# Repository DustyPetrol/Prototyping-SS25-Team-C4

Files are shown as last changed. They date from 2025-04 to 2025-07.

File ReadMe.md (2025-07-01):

# Prototyping SS25 Group C4

## [Final Report](Documentation/FinalReport/main.pdf)

## Distribution of tasks

| № | Task | Short summary | Responsible person | Deadline | Status |
|:---|:---|:---|:---|:---|:---|
| **1**  | 3D-modelling | Model and submit parts for 3D-printing: <br/> - motor holders<br/> - IR-sensor holders<br/> - battery/breadboard holder | [Oleg Kelner](https://github.com/eggcitedraccoon) | 24.04.25 | ✅ *Done* |
| **2**  | Requirements Diagram  | Create Requirements Diagram for the prototype | [Petr Lavrenov](https://github.com/DustyPetrol) | 27.04.25 | ✅ *Done* |
| **3**  | Use Case Diagram | Create Use Case Diagram for the prototype | [Petr Lavrenov](https://github.com/DustyPetrol) | 04.05.25 | ✅ *Done* |
| **4**  | Structure Diagram | Create Structure diagram for the prototype | [Petr Lavrenov](https://github.com/DustyPetrol) | 04.05.25 | ✅ *Done* |
| **5**  | State Machine Diagram | Create State Machine Diagram for the prototype | [Petr Lavrenov](https://github.com/DustyPetrol) | 04.05.25 | ✅ *Done* |
| **6**  | Tinkercad Simulation  | Create Tinkercad simulation of the prototype | [Oleg Kelner](https://github.com/eggcitedraccoon) | 04.05.25 | ✅ *Done* |
| **7**  | Assembling | Assemble the prototype: <br/> - fix 3D-printed parts on the chassis<br/> - solder power wires<br/> - connect everything | [Oleg Kelner](https://github.com/eggcitedraccoon) | 08.05.25 | ✅ *Done* |
| **8**  | 3D-modelling | Model and submit parts for 3D-printing: <br/> - ultrasonic holder<br/> - servo holder | [Oleg Kelner](https://github.com/eggcitedraccoon) | 05.05.25 | ✅ *Done* |
| **9**  | Programming | Make it follow the line | [Petr Lavrenov](https://github.com/DustyPetrol) | 15.05.25 | ✅ *Done* |
| **10** | Sequence Diagram | Create Sequence Diagram for the prototype | [Turja Barua](https://github.com/TurjabaruaGit) | 04.05.25 | ✅ *Done* |
| **11** | 3D-modelling | Model and submit parts for 3D-printing:<br/> - RGB-sensor holder | [Oleg Kelner](https://github.com/eggcitedraccoon) | 21.05.25 | ✅ *Done* |
| **12** | Programming | Unit tests | [Turja Barua](https://github.com/TurjabaruaGit) | 21.05.25 | ✅ *Done* |
| **13** | Programming | Implement `checkColor()` function | [Oleg Kelner](https://github.com/eggcitedraccoon) | 30.05.25 | ✅ *Done* |
| **14** | Programming | Implement *follow line* state machine | [Petr Lavrenov](https://github.com/DustyPetrol) | 30.05.25 | ✅ *Done* |
| **15** | Report | Prepare final project report | [Turja Barua](https://github.com/TurjabaruaGit) | 22.06.25 | ✅ *Done* |

## Project structure

### Documentation

```
Documentation/
|— Lectures/
|— Papyrus/
|— TinkerCad/
|— Assembly.png
```

`Lectures` contain lectures and other materials given by professors.

`Papyrus` contain **Papyrus** project with *SysML* diagrams.

`TinkerCad` contain **TinkerCad** simulation files (pic of the circuit and code).

`Assembly.png` - picture of the assembled prototype in 3D-modelling software.

### 3D models

```
3D models/
|— Basic components/
|— Details to print/
|— Assembly.iam 
```

`Basic components` contain 3D models of given components, such as Arduino Uno, battery, motors etc.

`Details to print` contain 3D-modeled parts for the printing (motor holder, IR-sensor holder etc.).

`Assembly.iam` - an assembly of the prototype made in **Autodesk Inventor**.

### Software

```
Software/
|— src/src.ino
```

`src/src.ino` - Arduino IDE main file.

## Additional materials

Useful **[Led Matrix Editor](https://ledmatrix-editor.arduino.cc/)**

**[Color sensor documentation](https://cdn-reichelt.de/documents/datenblatt/A300/SEN-COLOR_MANUAL_2021-08-18.pdf)**

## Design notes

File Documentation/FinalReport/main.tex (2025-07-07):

\documentclass[conference]{IEEEtran}
\IEEEoverridecommandlockouts

\usepackage{cite}
\usepackage{amsmath,amssymb,amsfonts}
\usepackage{algorithmic}
\usepackage{graphicx}
\usepackage{textcomp}
\usepackage{xcolor}
\usepackage{hyperref}
\usepackage{listings}
\usepackage{float}

\newcommand{\BibTeX}{\textrm{B \kern -.05em \textsc{i \kern -.025em b} \kern -.08em
T \kern -.1667em \lower .7ex \hbox{E} \kern -.125emX}}

\begin{document}

    \title{Design and Implementation of a Line Following and Obstacle Avoidance Robot}

    \author{
        \IEEEauthorblockN{Oleg Kelner\IEEEauthorrefmark{1}, Petr Lavrenov\IEEEauthorrefmark{1}, Turja Barua\IEEEauthorrefmark{1}}
        \IEEEauthorblockA{\IEEEauthorrefmark{1}Systems Engineering and Prototyping, BSc Electronic Engineering\\
        Hochschule Hamm-Lippstadt, Lippstadt, Germany\\
        \{oleg.kelner, petr.lavrenov, turja.barua\}@stud.hshl.de}
    }

    \maketitle

    \begin{abstract}
        This paper presents the design, development, and implementation of an autonomous mobile robot capable of both line following and obstacle avoidance. The project was conducted as part of a university prototyping course, focusing on integrating hardware components such as infrared sensors, ultrasonic modules, and servo motors with an Arduino-based control system. The robot's behavior is governed by a state machine model to ensure reliable navigation and quick response to environmental changes. Supporting tools like 3D modeling for hardware mounting, Tinkercad for simulation, and SysML for system-level design were used throughout the development process. The final prototype demonstrates effective performance in real-time scenarios, providing a practical understanding of embedded systems, control logic, and systems engineering principles.
    \end{abstract}

    \begin{IEEEkeywords}
        Autonomous robot, Line following, Obstacle avoidance, Arduino, Embedded systems, Infrared sensor, Ultrasonic sensor.
    \end{IEEEkeywords}

    \section{Introduction}\label{sec:introduction}

    This project focuses on building a simple autonomous robot that can follow a line and avoid obstacles using basic sensors. The robot is controlled by an Arduino Uno and uses infrared sensors to detect the line and an ultrasonic sensor to measure distance from obstacles. We used a step-by-step design process that included system modeling, 3D printing of parts, and simulation in Tinkercad. A state machine was used in the software to control how the robot switches between line-following and obstacle-avoidance modes. The goal was to learn how to combine hardware and software to create a working prototype.
    \section{System Design and Engineering}\label{sec:system-design-and-engineering}
    \begin{figure}[H]
        \centering
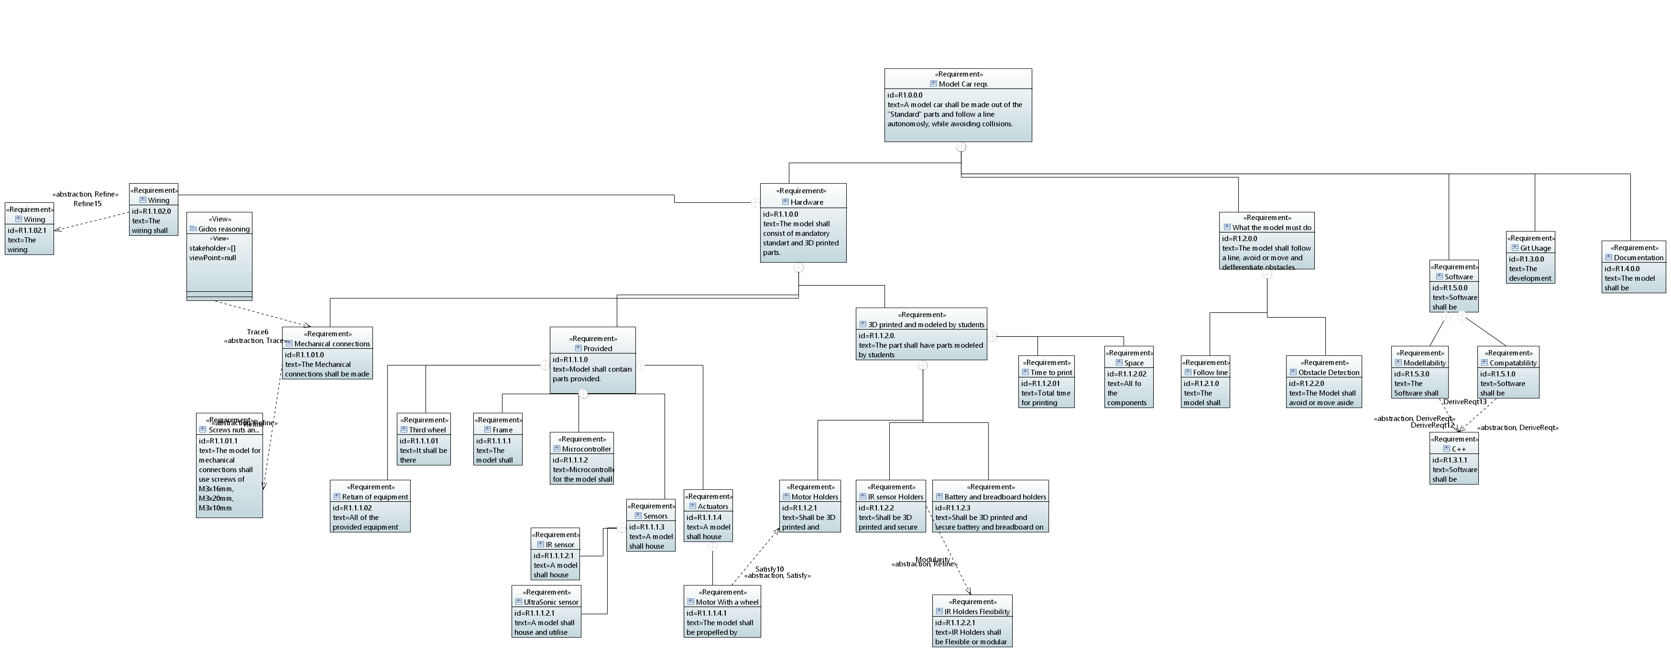
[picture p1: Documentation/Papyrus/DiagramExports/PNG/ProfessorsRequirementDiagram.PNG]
        
        \caption{ProfessorsRequirementDiagram (full page view in Appendix A)}
    \end{figure}
    \begin{figure}[H]
        \centering
        \begin{minipage}{0.48\linewidth}
            \centering
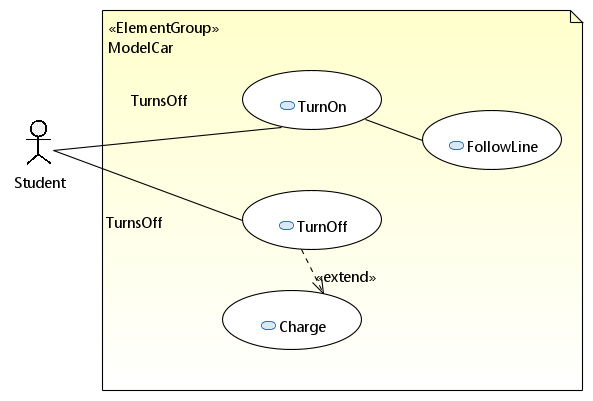
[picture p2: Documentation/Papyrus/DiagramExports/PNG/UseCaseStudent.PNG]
            
            \caption{Use Case Diagram(Student)}
            \label{fig:usecase_student}
        \end{minipage}
        \hfill
        \begin{minipage}{0.48\linewidth}
            \centering
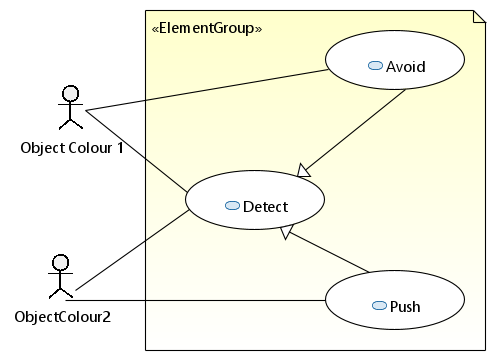
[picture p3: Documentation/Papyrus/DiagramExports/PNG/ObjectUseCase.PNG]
            
            \caption{Use Case Diagram(Object-Oriented)}
            \label{fig:object_usecase}
        \end{minipage}
    \end{figure}

    \begin{figure}[H]
        \centering
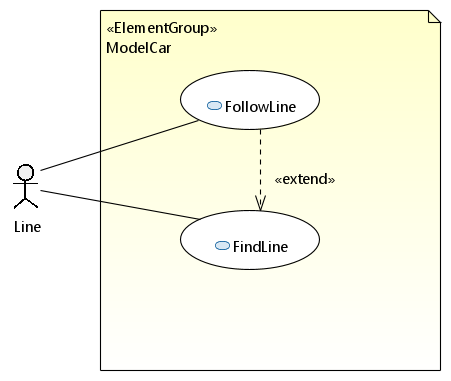
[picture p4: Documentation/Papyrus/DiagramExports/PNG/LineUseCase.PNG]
        
        \caption{LineUseCase}
        \label{fig:line_usecase}
    \end{figure}

    \begin{figure}[H]
        \centering
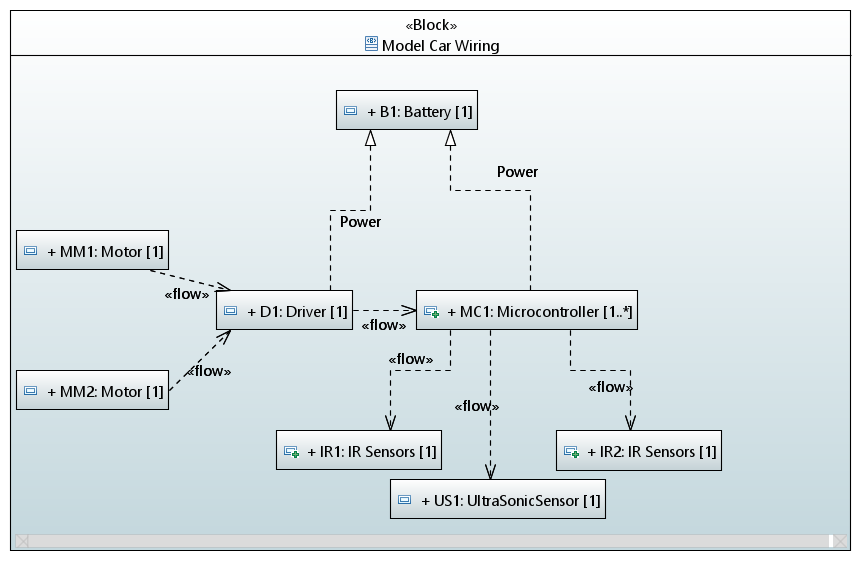
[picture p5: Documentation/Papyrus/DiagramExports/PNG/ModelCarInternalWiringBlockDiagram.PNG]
        
        \caption{ModelCarInternalWiringBlockDiagram}
        \label{fig:ModelCarInternalWiring_BlockDiagraml}
    \end{figure}
    \begin{figure}[H]
        \centering
        \begin{minipage}{0.48\linewidth}
            \centering
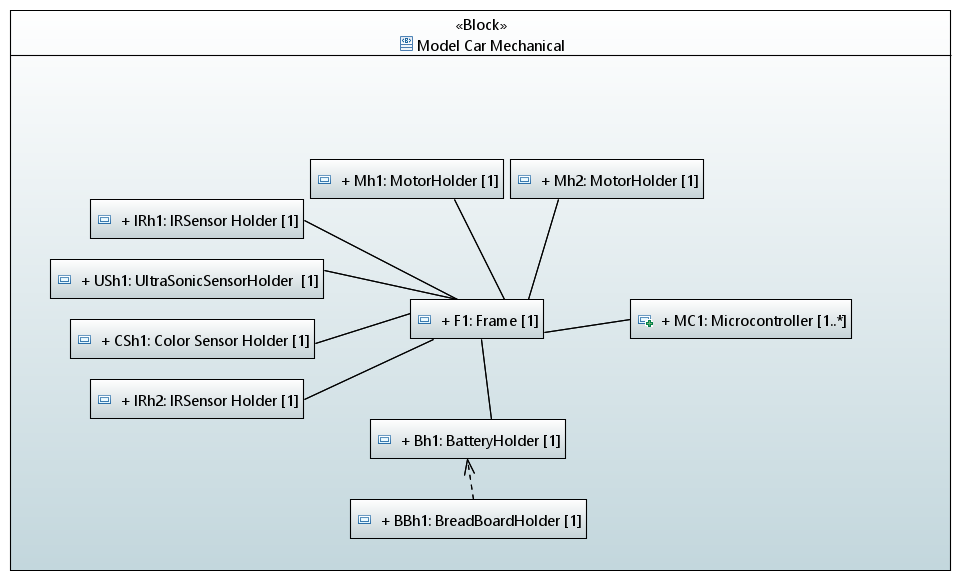
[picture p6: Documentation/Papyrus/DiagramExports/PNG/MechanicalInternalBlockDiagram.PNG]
            
            \caption{Mechanical Internal Block Diagram}
            \label{fig:MechanicalInternal_BlockDiagram}
        \end{minipage}
        \hfill
        \begin{minipage}{0.48\linewidth}
            \centering
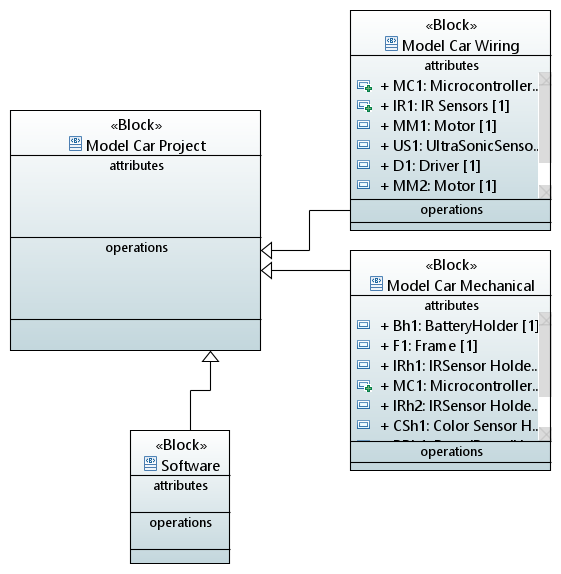
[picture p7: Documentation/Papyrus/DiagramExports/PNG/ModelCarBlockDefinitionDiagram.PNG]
            
            \caption{Model Car Block Definition Diagram}
            \label{fig:ModelCarDiagram_BlockDefinition}
        \end{minipage}
    \end{figure}

    \section{Prototyping and Design}\label{sec:prototyping-and-design}

    \subsection{Electronic Components}\label{subsec:electronic-components}
    The robot was built using a combination of basic electronic components. An Arduino Uno served as the central controller, processing sensor inputs and controlling the motors. Infrared (IR) sensors were used to detect the line path, while an ultrasonic sensor was employed for obstacle detection. A pair of DC motors provided movement, and the motor driver controlled their direction and speed. A breadboard and jumper wires were used to connect all components during testing and prototyping.

    \subsection{Virtual and Physical Prototypes}\label{subsec:virtual-and-physical-prototypes}
    All components were mounted onto a custom laser-cut wooden chassis. The Arduino board, breadboard, and motor driver were securely placed, and wiring was organized for stable operation. The ultrasonic sensor is mounted on a servo motor to allow directional scanning. The wheels are driven by DC motors placed at the rear, and all parts are powered via a shared voltage rail.
    \begin{figure}[H]
        \centering
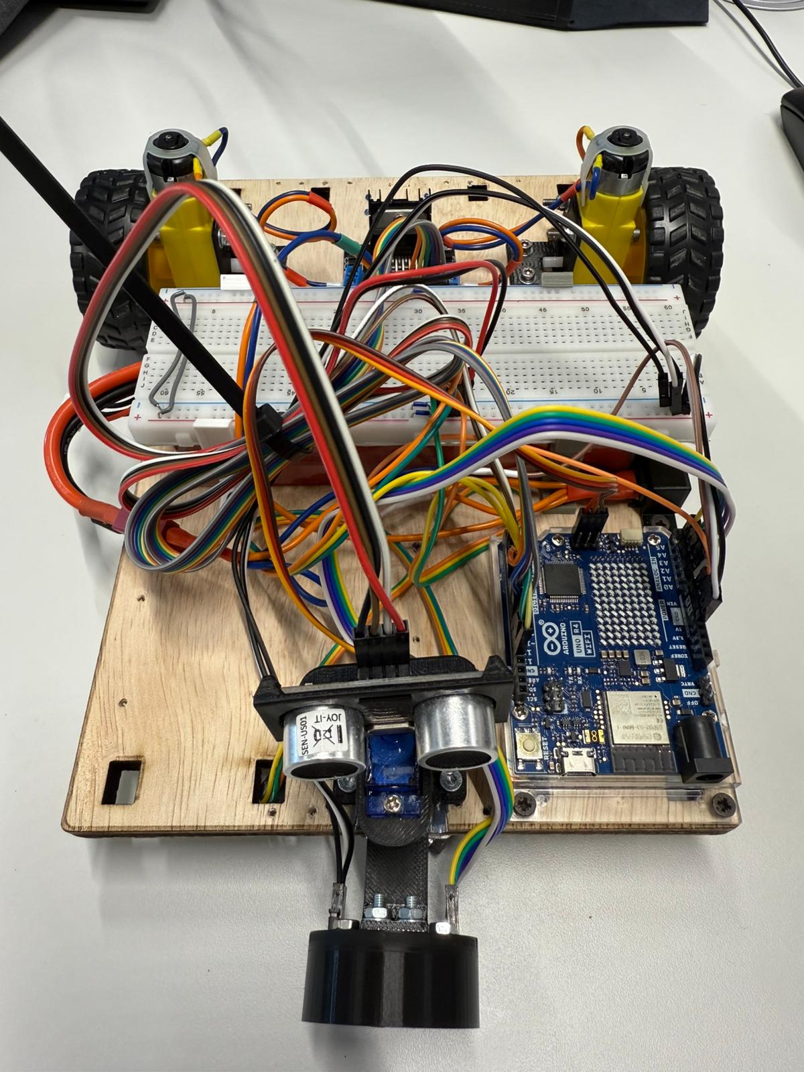
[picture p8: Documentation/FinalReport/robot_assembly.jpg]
        
        \caption{Robot Assembly}
    \end{figure}

    \subsection{Hardware Assembly}\label{subsec:hardware-assembly}
    All components were securely mounted on a custom-designed chassis and connected according to the system schematic. The IR sensors, ultrasonic sensor, motor driver, and Arduino Uno were all arranged for optimal functionality and accessibility.
    To better suit the physical layout and wiring constraints, the entire robot assembly was reversed, meaning the front-facing sensors and drive motors were reoriented to face the opposite direction. This design change ensured improved cable management, balanced weight distribution, and more efficient component interaction during operation.

    \begin{figure}[H]
        \centering
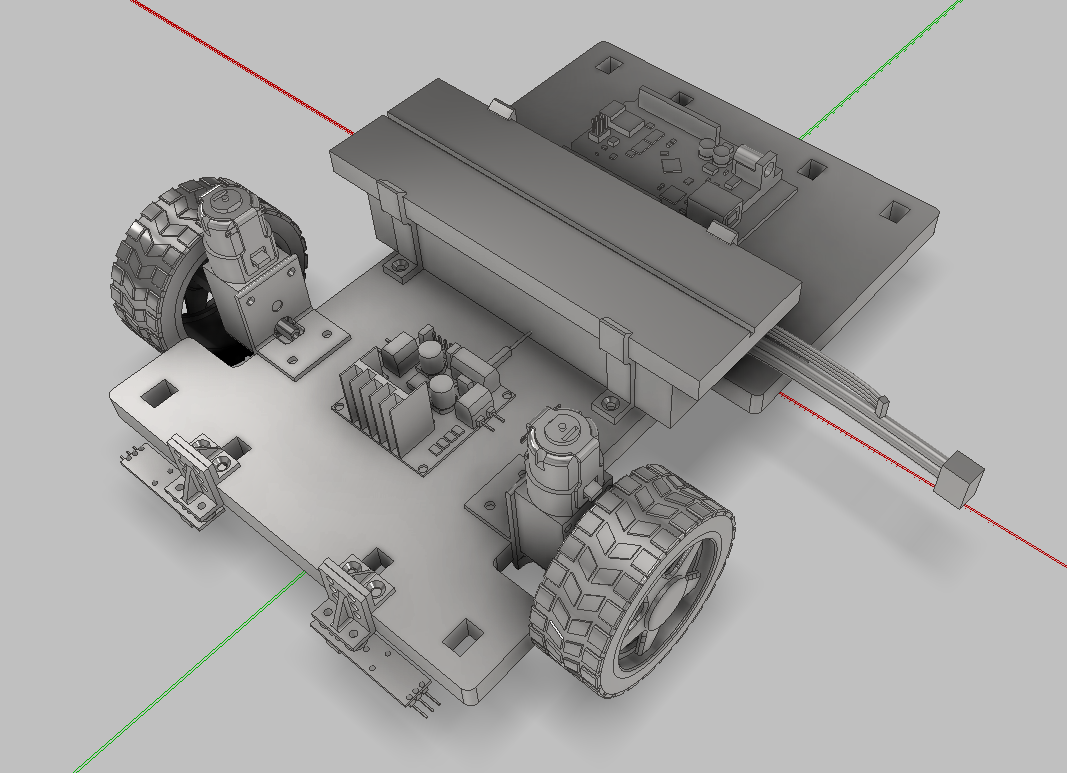
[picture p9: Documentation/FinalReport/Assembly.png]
        
        \caption{Assembly}
    \end{figure}
    \begin{figure}[H]
        \centering
        \begin{minipage}{0.48\linewidth}
            \centering
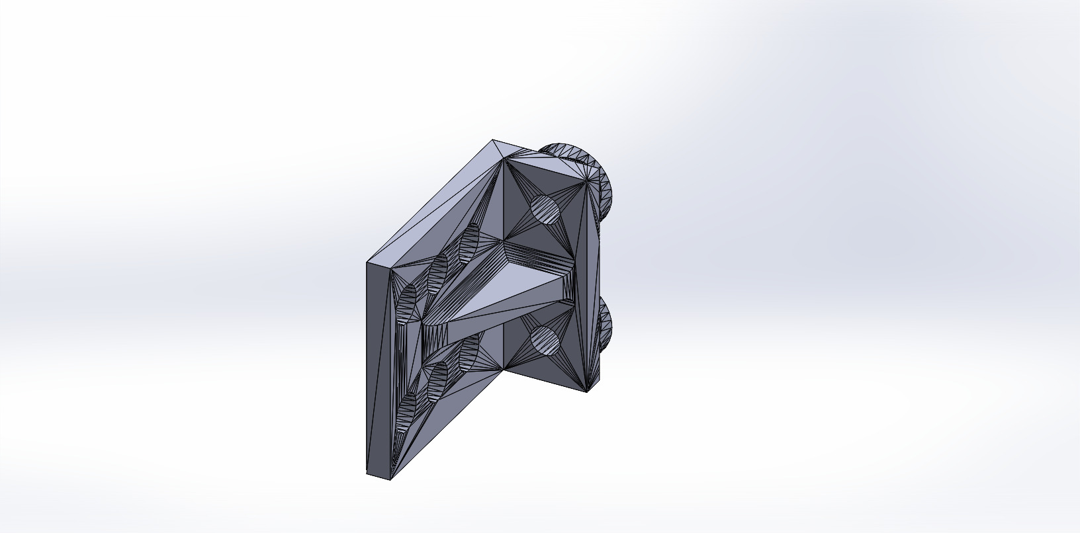
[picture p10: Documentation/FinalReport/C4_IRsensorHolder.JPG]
            
            \caption{IR Sensor Holder 1}
            \label{fig:IRsensorHolder1}
        \end{minipage}
        \hfill
        \begin{minipage}{0.48\linewidth}
            \centering
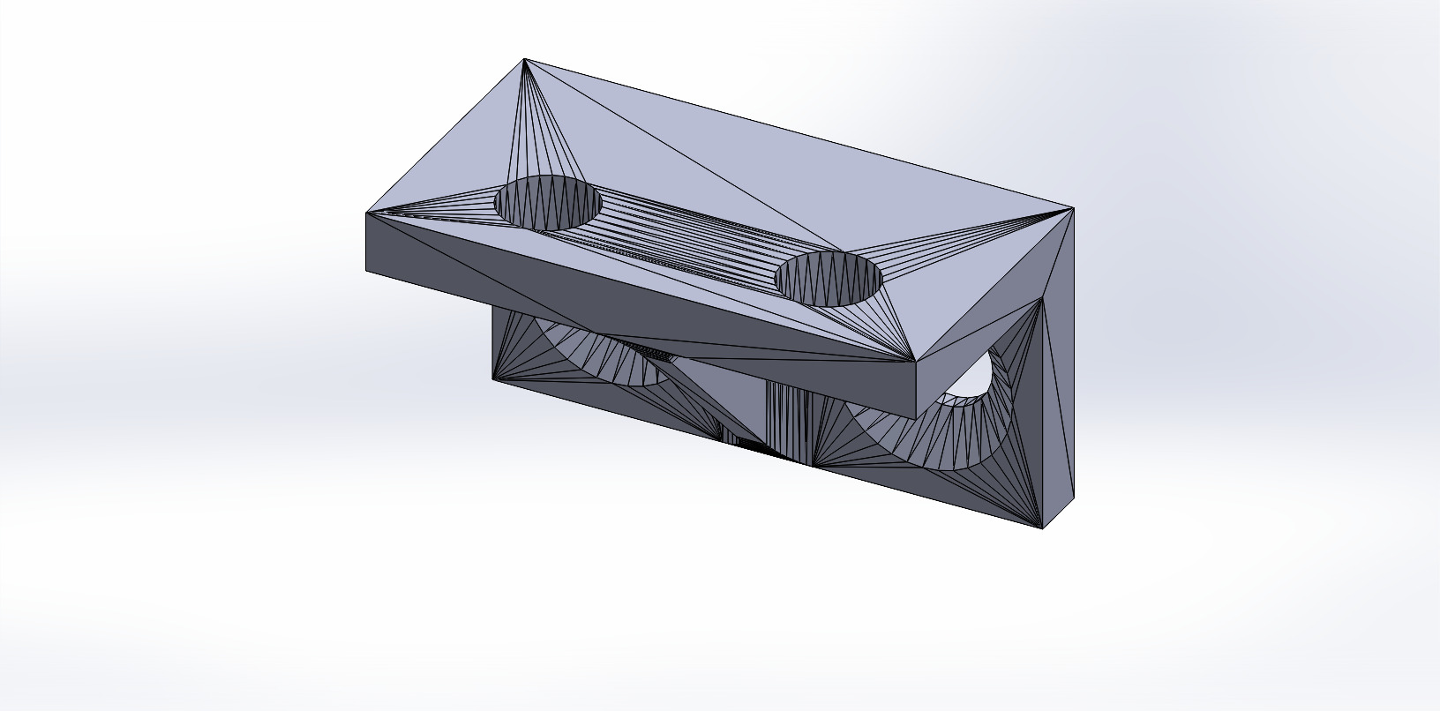
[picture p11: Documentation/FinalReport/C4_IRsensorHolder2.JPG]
            
            \caption{IR Sensor Holder 2}
            \label{fig:IRsensorHolder2}
        \end{minipage}
    \end{figure}

    \section{Circuit Design}\label{sec:circuit-design}
    \begin{figure}[H]
        \centering
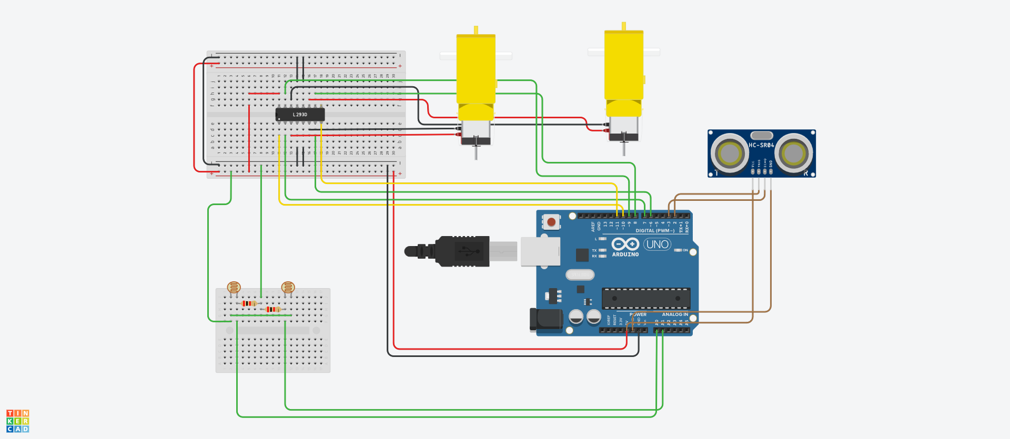
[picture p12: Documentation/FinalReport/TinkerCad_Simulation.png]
        
        \caption{TinkerCad Simulation}
    \end{figure}
    \subsection*{Circuit Simulation Layout:}
    The TinkerCad simulation shows the practical wiring of the robot's components on a breadboard. The Arduino Uno is connected to an motor driver IC for motor control, while IR sensors detect line position and the ultrasonic sensor handles distance measurement. All connections are routed through the breadboard with clear separation between power and control lines for easy testing and debugging.

    \begin{figure}[H]
        \centering
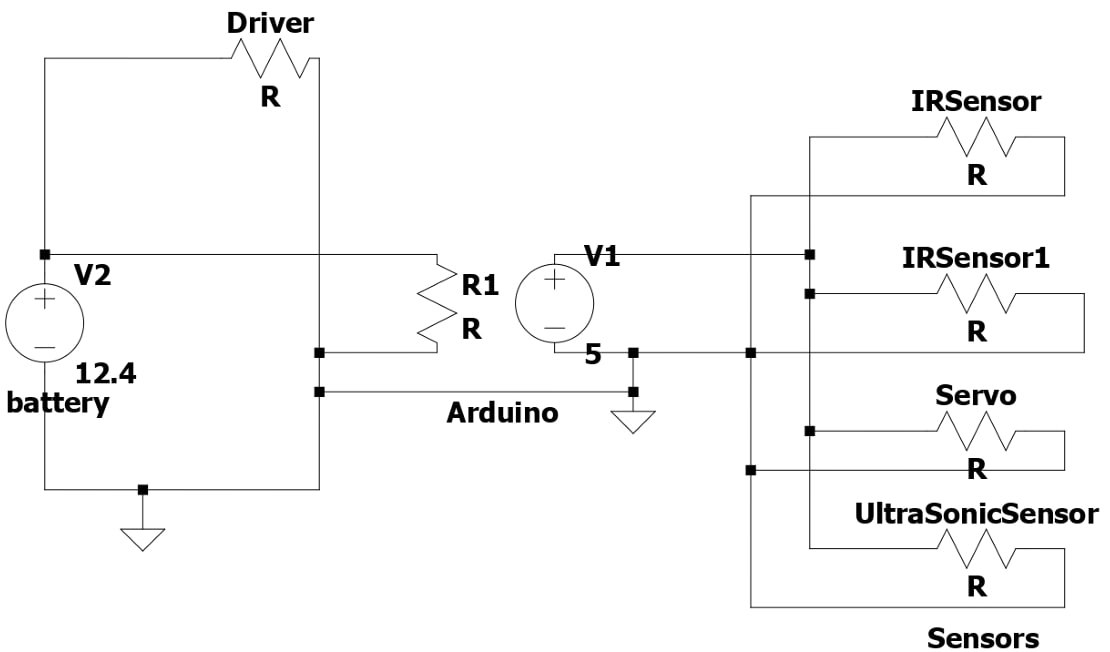
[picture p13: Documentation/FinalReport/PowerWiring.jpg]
        
        \caption{Power Wiring}
    \end{figure}
    \subsection*{Power Supply Configuration}
    The power wiring diagram models the voltage distribution of the system. A 12.4V battery supplies power to the motor driver, while the Arduino Uno regulates and provides a 5V output to power the sensors and other components. The IR sensors, ultrasonic sensor, and servo motor are connected in parallel to the Arduino's 5V and GND pins. Proper wiring and current distribution ensure safe and stable operation of all modules.

%\begin{itemize}
    %   \item The schematic includes sensors, motor driver, Arduino, and power source.
    %  \item Wiring includes proper voltage connections and pin mappings for sensors and motors.
%\end{itemize}

%\begin{figure}[htbp]
%\centerline{\includegraphics[width=0.9\linewidth]{circuit_diagram.png}}
%\caption{Complete circuit layout of the robot}
%\label{fig:circuit}
%\end{figure}

    \section{Software Implementation}
    \label{sec:soft}

    \subsection{Initialization of Sensors and Actuators}\label{subsec:initialization-of-sensors-and-actuators}
    Pins for sensors were defined and initialized in the `setup()` function. Below is a snippet:
    \begin{lstlisting}[language=C++, caption=Sensor Initialization Code,label={lst:lstlisting}]
/**
 * @brief Initialize all pins and components
 *
 * Sets up pin modes for motors, sensors,
 * and initializes servo and LED matrix
 */
void Robot::init() {
  Serial.begin(9600);

  // Set motor control pins as outputs
  pinMode(ENA, OUTPUT);
  pinMode(ENB, OUTPUT);
  pinMode(IN1, OUTPUT);
  pinMode(IN2, OUTPUT);
  pinMode(IN3, OUTPUT);
  pinMode(IN4, OUTPUT);

  // Set IR sensors as inputs
  pinMode(IR_LEFT, INPUT);
  pinMode(IR_RIGHT, INPUT);

  // Set ultrasonic sensor pins
  pinMode(TRIGGER_PIN, OUTPUT);
  pinMode(ECHO_PIN, INPUT);

  // Set color sensor pins
  pinMode(S0, OUTPUT);
  pinMode(S1, OUTPUT);
  pinMode(S2, OUTPUT);
  pinMode(S3, OUTPUT);
  pinMode(sensorOut, INPUT);

  // Set frequency scaling to 20%
  // for color sensor
  digitalWrite(S0, HIGH);
  digitalWrite(S1, LOW);

  // Initialize servo and LED matrix
  myservo.attach(SERVO);
  matrix.begin();

  // Initialize error timer
  timerError = millis();
}
    \end{lstlisting}

    \subsection{Movement Control Algorithms}\label{subsec:movement-control-algorithms}
    \begin{figure}[H]
        \centering
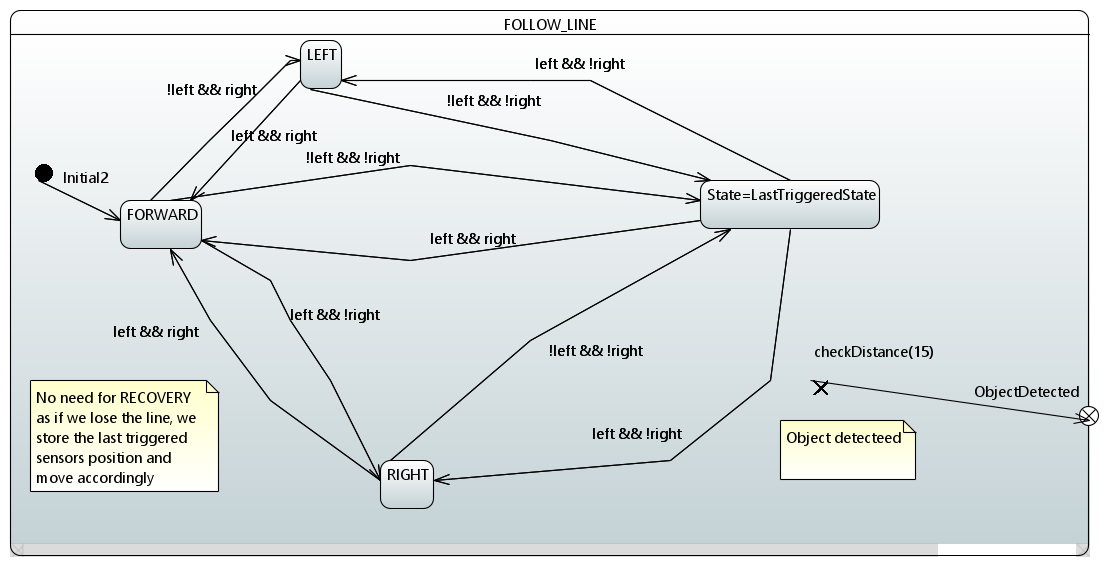
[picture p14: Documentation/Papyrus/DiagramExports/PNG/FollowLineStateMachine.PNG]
        
        \caption{FollowLineStateMachine}
        \label{fig:enter-label}
    \end{figure}
    \textbf{1. Follow Line State Machine:}
    This state machine guides the robot along a line using infrared sensors. It starts in the \texttt{GoForward} state and continues as long as both sensors are on or off the line. If the left sensor detects the line, it transitions to \texttt{GoLeft}; if the right sensor detects the line, it moves to \texttt{GoRight}. If neither sensor sees the line, it defaults to last recorded state.

    \begin{figure}[H]
        \centering
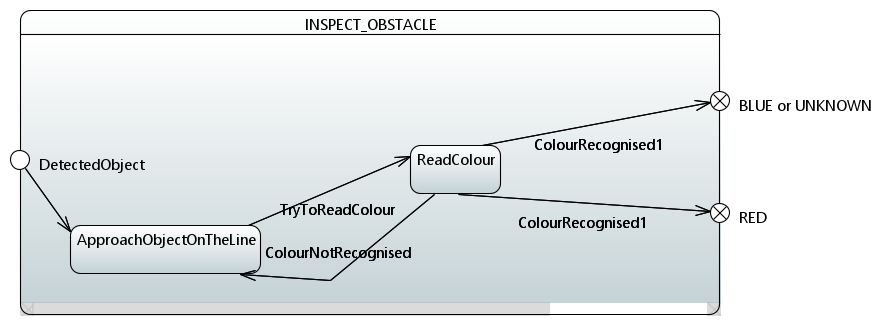
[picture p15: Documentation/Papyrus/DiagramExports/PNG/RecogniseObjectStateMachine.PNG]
        
        \caption{Recognise Object State Machine}
        \label{fig:recogniseobject_statemachine}
    \end{figure}
    \textbf{2. Recognise Object State Machine:}
    This logic is activated when the robot detects an object. It first enters the \texttt{ApproachObjectOnTheLine} state, then attempts to read the color in \texttt{ReadColour}. Based on the result, it transitions to either \texttt{Colour1} or \texttt{Colour2}, or loops back if the color is not recognized. This helps determine how the robot should react to different objects.

    \subsection{Behavioral Decision Logic}\label{subsec:behavioral-decision-logic}
    \begin{figure}[H]
        \centering
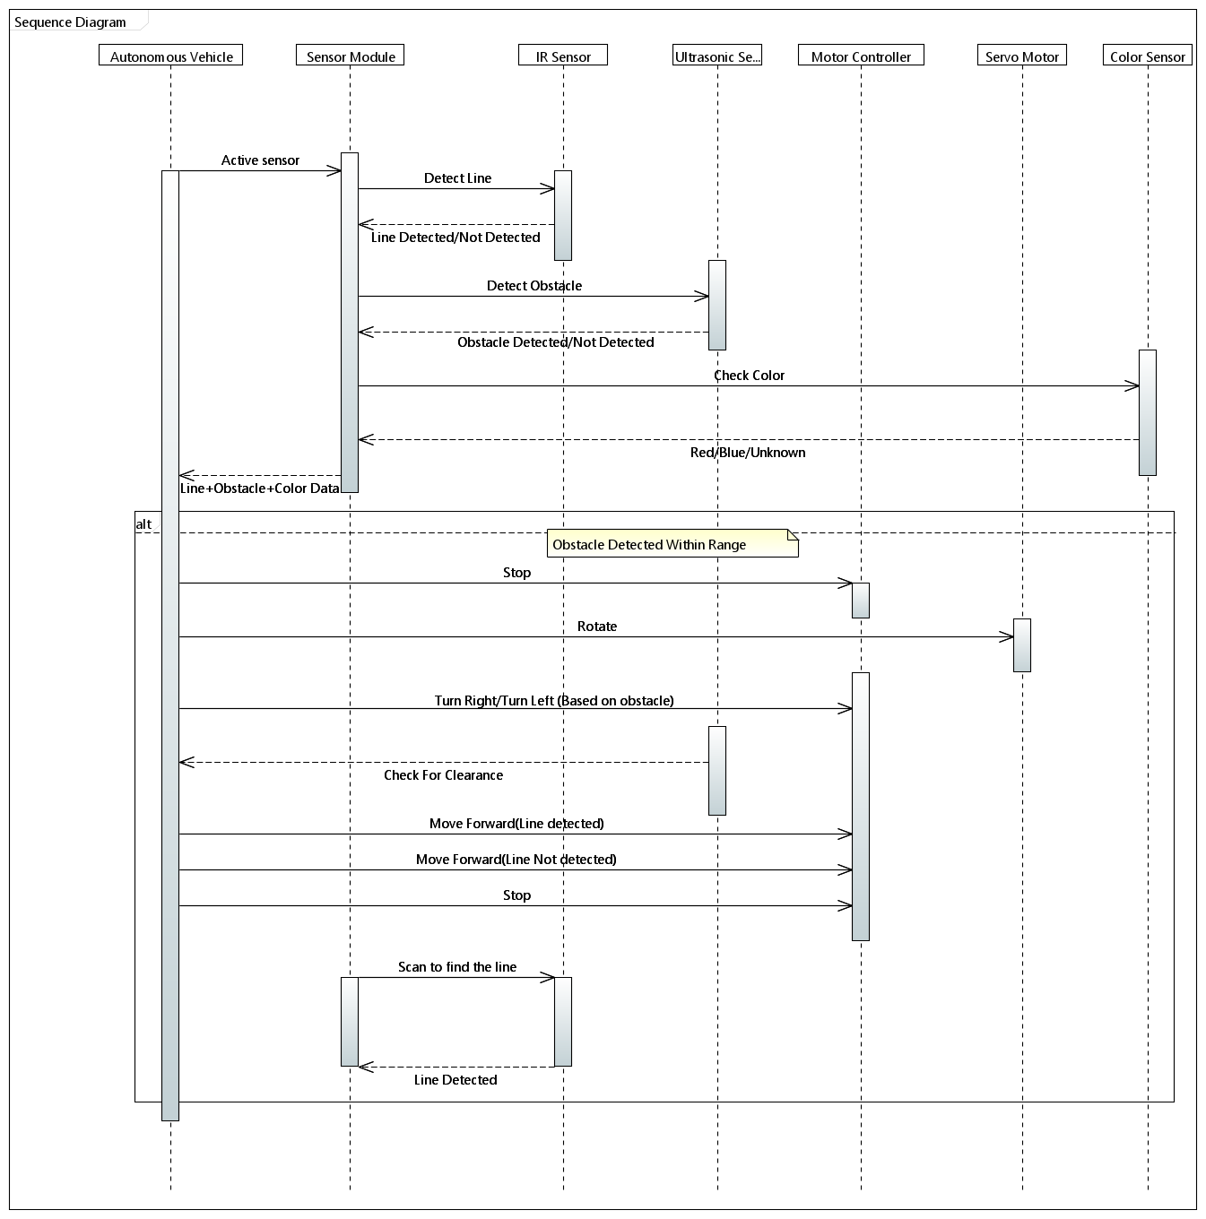
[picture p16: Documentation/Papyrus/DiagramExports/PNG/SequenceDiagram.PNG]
        
        \caption{SequenceDiagram (full page view in Appendix B)}
        \label{fig:Sequence_Diagram}
    \end{figure}
    \textbf{1. Sequence Diagram:}
    This diagram illustrates how components interact over time. The IR sensor detects line positions, while the ultrasonic sensor checks for obstacles. Both send data to the microcontroller, which processes it to control the motors. If an obstacle is detected, the system initiates an avoidance routine and then resumes line following, ensuring continuous decision-making.
    \begin{figure}[H]
        \centering
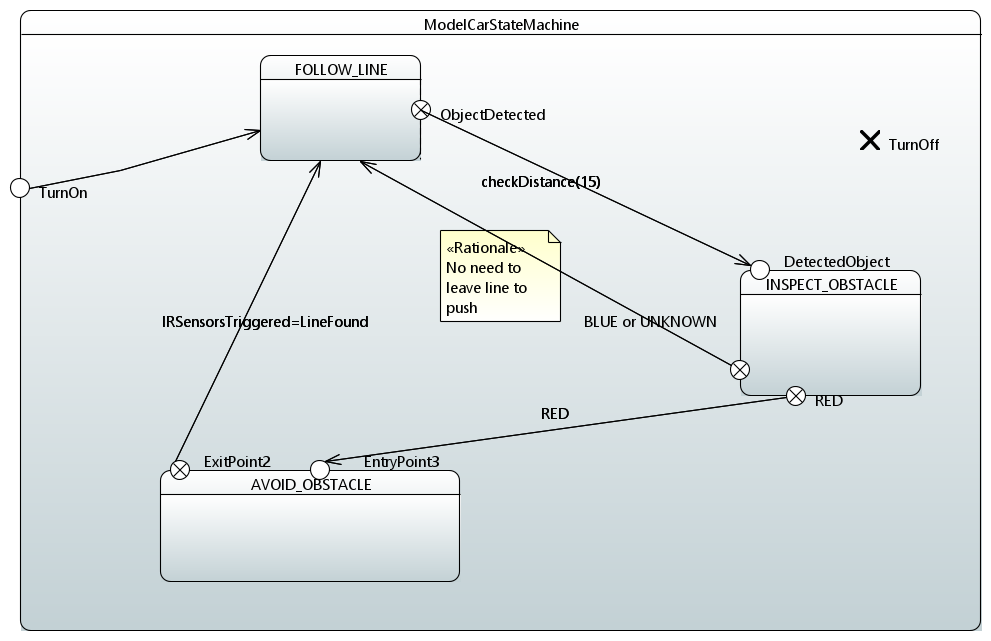
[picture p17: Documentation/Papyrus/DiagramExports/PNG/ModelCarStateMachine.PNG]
        
        \caption{ModelCarStateMachine}
        \label{fig:modelcar_statemachine}
    \end{figure}
    \textbf{2. Model Car State Machine:}
    The state machine shows high-level decision-making. The robot starts in the \texttt{Follow Line} state. Upon detecting an object, it transitions to \texttt{RecogniseObject}. Based on the detected color, it either continues pushing (Color1) or avoids the object (Color2). After avoiding, it returns to line following. This logic enables adaptive behavior based on environmental inputs.
    \section{Git Usage and Collaboration}\label{sec:git-usage-and-collaboration}
    Project development was tracked using GitHub.

    \begin{table}[ht]
        \centering
        \begin{tabular}{l|c}
            \hline
            \textbf{Team Member} & \textbf{Number of Commits} \\
            \hline
            Oleg Kelner     & 77 \\
            Petr Lavrenov     & 57  \\
            Turja Barua     & 11  \\
            \hline
            \textbf{Total} & \textbf{145} \\
            \hline
        \end{tabular}
        \caption{GitHub Commits by Team Members}
        \label{tab:commit}
    \end{table}

    \section{Key Achievements}\label{sec:key-achievements}
    \begin{itemize}
        \item The robot successfully follows a predefined path using IR sensors.
        \item It can accurately differentiate between colors using an onboard color sensor.
        \item It is capable of detecting and avoiding obstacles in real-time using an ultrasonic sensor.
    \end{itemize}
    \section{Acknowledgment}\label{sec:acknowledgment}
    We would like to express our sincere gratitude to our course instructor and project supervisor for their continuous guidance and valuable feedback throughout the development of this project. We are also thankful to Hochschule Hamm-Lippstadt for providing the tools, resources, and a collaborative environment that made this work possible. Lastly, we appreciate the teamwork and commitment of all group members in bringing this project to completion.

    \begin{thebibliography}{00}
        \bibitem{arduino} Arduino Documentation. \url{https://www.arduino.cc/en/Guide}
        \bibitem{tinkercad} Tinkercad Simulation. \url{https://www.tinkercad.com}
        \bibitem{uppaal} Uppaal Model Checker. \url{https://www.uppaal.org/}
    \end{thebibliography}

    \section*{Declaration of Originality}
    We hereby declare that this report is our own work and that we have acknowledged all sources used.

    % Now switch to one column for appendix image
    \clearpage
    \twocolumn[{
        \begin{center}
            \section*{Appendix A: ProfessorsRequirementDiagram}
            
        \end{center}
    }]

    \clearpage
    \twocolumn[{
        \begin{center}
            \section*{Appendix B: SequenceDiagram}
            
        \end{center}
    }]

\end{document}

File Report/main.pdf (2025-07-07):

# Design and Implementation of a Line Following and Obstacle Avoidance Robot

Oleg Kelner∗

, Petr Lavrenov∗

, Turja Barua∗
∗Systems Engineering and Prototyping, BSc Electronic Engineering Hochschule Hamm-Lippstadt, Lippstadt, Germany {oleg.kelner, petr.lavrenov, turja.barua}@stud.hshl.de

Abstract—This paper presents the design, development, and implementation of an autonomous mobile robot capable of both line following and obstacle avoidance. The project was conducted as part of a university prototyping course, focusing on integrating hardware components such as infrared sensors, ultrasonic modules, and servo motors with an Arduino-based control system. The robot’s behavior is governed by a state machine model to ensure reliable navigation and quick response to environmental changes. Supporting tools like 3D modeling for hardware mounting, Tinkercad for simulation, and SysML for system-level design were used throughout the development process. The final prototype demonstrates effective performance in real-time scenarios, providing a practical understanding of embedded systems, control logic, and systems engineering principles.
Index Terms—Autonomous robot, Line following, Obstacle avoidance, Arduino, Embedded systems, Infrared sensor, Ultrasonic sensor.
I. INTRODUCTION

This project focuses on building a simple autonomous robot that can follow a line and avoid obstacles using basic sensors. The robot is controlled by an Arduino Uno and uses infrared sensors to detect the line and an ultrasonic sensor to measure distance from obstacles. We used a step-by-step design process that included system modeling, 3D printing of parts, and simulation in Tinkercad. A state machine was used in the software to control how the robot switches between line-following and obstacle-avoidance modes. The goal was to learn how to combine hardware and software to create a working prototype.

II. SYSTEM DESIGN AND ENGINEERING


Fig. 1. ProfessorsRequirementDiagram (full page view in Appendix A)

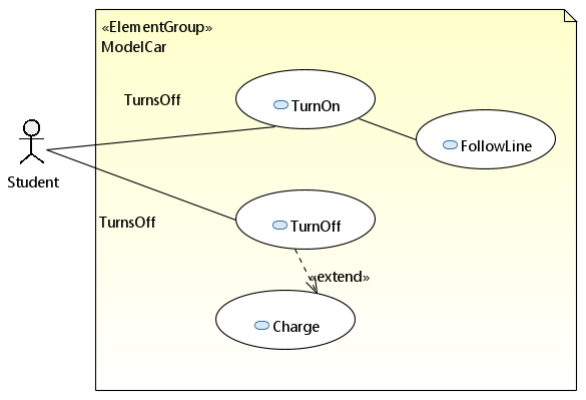
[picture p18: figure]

Fig. 2. Use Case Diagram(Student) Fig. 3. Use Case Diagram(Object- Oriented)


Fig. 4. LineUseCase


Fig. 5. ModelCarInternalWiringBlockDiagram


Fig. 6. Mechanical Internal Block Diagram


Fig. 7. Model Car Block Definition Diagram

III. PROTOTYPING AND DESIGN

A. Electronic Components
The robot was built using a combination of basic electronic components. An Arduino Uno served as the central controller, processing sensor inputs and controlling the motors. Infrared (IR) sensors were used to detect the line path, while an ultrasonic sensor was employed for obstacle detection. A pair of DC motors provided movement, and the motor driver controlled their direction and speed. A breadboard and jumper wires were used to connect all components during testing and prototyping.
B. Virtual and Physical Prototypes
All components were mounted onto a custom laser-cut wooden chassis. The Arduino board, breadboard, and motor driver were securely placed, and wiring was organized for stable operation. The ultrasonic sensor is mounted on a servo motor to allow directional scanning. The wheels are driven by DC motors placed at the rear, and all parts are powered via a shared voltage rail.


Fig. 8. Robot Assembly

C. Hardware Assembly
All components were securely mounted on a customdesigned chassis and connected according to the system schematic. The IR sensors, ultrasonic sensor, motor driver, and Arduino Uno were all arranged for optimal functionality and accessibility. To better suit the physical layout and wiring constraints, the entire robot assembly was reversed, meaning the front-facing sensors and drive motors were reoriented to face the opposite direction. This design change ensured improved cable management, balanced weight distribution, and more efficient component interaction during operation.


Fig. 9. Assembly

Fig. 10. IR Sensor Holder 1 | Fig. 11. IR Sensor Holder 2

IV. CIRCUIT DESIGN

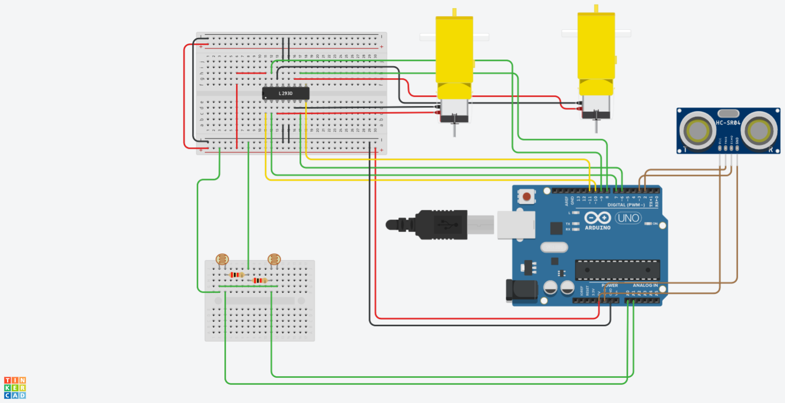
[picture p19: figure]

Fig. 12. TinkerCad Simulation

Circuit Simulation Layout:

The TinkerCad simulation shows the practical wiring of the robot’s components on a breadboard. The Arduino Uno is connected to an motor driver IC for motor control, while IR sensors detect line position and the ultrasonic sensor handles distance measurement. All connections are routed through the breadboard with clear separation between power and control lines for easy testing and debugging.


Fig. 13. Power Wiring

Power Supply Configuration
The power wiring diagram models the voltage distribution of the system. A 12.4V battery supplies power to the motor driver, while the Arduino Uno regulates and provides a 5V output to power the sensors and other components. The IR sensors, ultrasonic sensor, and servo motor are connected in parallel to the Arduino’s 5V and GND pins. Proper wiring and current distribution ensure safe and stable operation of all modules.
V. SOFTWARE IMPLEMENTATION
A. Initialization of Sensors and Actuators
Pins for sensors were defined and initialized in the ‘setup()‘ function. Below is a snippet:

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

/ / S e t motor c o n t r o l p i n s as o u t p u t s pinMode (ENA, OUTPUT ) ;
pinMode (ENB, OUTPUT ) ;
pinMode ( IN1 , OUTPUT ) ;
pinMode ( IN2 , OUTPUT ) ; pinMode ( IN3 , OUTPUT ) ; pinMode ( IN4 , OUTPUT ) ;

/ / S e t IR s e n s o r s as i n p u t s pinMode ( IR LEFT , INPUT ) ; pinMode ( IR RIGHT , INPUT ) ;

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

/ / S e t c o l o r s e n s o r p i n s pinMode ( S0 , OUTPUT ) ;
pinMode ( S1 , OUTPUT ) ;

pinMode ( S2 , OUTPUT ) ;
pinMode ( S3 , OUTPUT ) ;
pinMode ( sensorOut , INPUT ) ;

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


Fig. 14. FollowLineStateMachine

### 1. Follow Line State Machine: This state machine guides

the robot along a line using infrared sensors. It starts in the GoForward state and continues as long as both sensors are on or off the line. If the left sensor detects the line, it transitions to GoLeft; if the right sensor detects the line, it moves to GoRight. If neither sensor sees the line, it defaults to last recorded state.

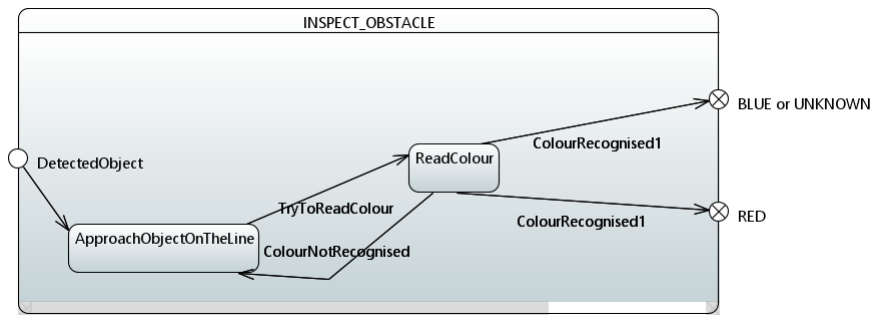
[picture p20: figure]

Fig. 15. Recognise Object State Machine

### 2. Recognise Object State Machine: This logic is ac-

tivated when the robot detects an object. It first enters the ApproachObjectOnTheLine state, then attempts to read the color in ReadColour. Based on the result, it transitions to either Colour1 or Colour2, or loops back if the color is not recognized. This helps determine how the robot should react to different objects.

C. Behavioral Decision Logic


Fig. 16. SequenceDiagram (full page view in Appendix B)

### 1. Sequence Diagram: This diagram illustrates how compo-

nents interact over time. The IR sensor detects line positions, while the ultrasonic sensor checks for obstacles. Both send data to the microcontroller, which processes it to control the motors. If an obstacle is detected, the system initiates an avoidance routine and then resumes line following, ensuring continuous decision-making.


Fig. 17. ModelCarStateMachine

### 2. Model Car State Machine: The state machine shows

high-level decision-making. The robot starts in the Follow Line state. Upon detecting an object, it transitions to RecogniseObject. Based on the detected color, it either continues pushing (Color1) or avoids the object (Color2). After avoiding, it returns to line following. This logic enables adaptive behavior based on environmental inputs.

VI. GIT USAGE AND COLLABORATION
Project development was tracked using GitHub.

VII. KEY ACHIEVEMENTS
- The robot successfully follows a predefined path using IR sensors.
Team Member | Number of Commits
Oleg Kelner | 77
Petr Lavrenov | 57
Turja Barua | 11
Total | 145 TABLE I

GITHUB COMMITS BY TEAM MEMBERS

- It can accurately differentiate between colors using an onboard color sensor.
- It is capable of detecting and avoiding obstacles in real-time using an ultrasonic sensor.

VIII. ACKNOWLEDGMENT
We would like to express our sincere gratitude to our course instructor and project supervisor for their continuous guidance and valuable feedback throughout the development of this project. We are also thankful to Hochschule Hamm-Lippstadt for providing the tools, resources, and a collaborative environment that made this work possible. Lastly, we appreciate the teamwork and commitment of all group members in bringing this project to completion.

REFERENCES

[1] Arduino Documentation. https://www.arduino.cc/en/Guide
[2] Tinkercad Simulation. https://www.tinkercad.com
[3] Uppaal Model Checker. https://www.uppaal.org/

DECLARATION OF ORIGINALITY
We hereby declare that this report is our own work and that we have acknowledged all sources used.

APPENDIX A: PROFESSORSREQUIREMENTDIAGRAM

APPENDIX B: SEQUENCEDIAGRAM

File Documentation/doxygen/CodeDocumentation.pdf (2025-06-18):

## Prototyping

Generated by Doxygen 1.9.4

1 Class Documentation | 1
1 Class Documentation | 1
2 File Documentation | 3
Index | 11

## 1 Class Documentation

### 1.1 Robot Class Reference

Main robot control class that handles line following, obstacle detection and avoidance.

#include <Robot.h>

Public Member Functions

- Robot (uint8_t ENA, uint8_t ENB, uint8_t IN1, uint8_t IN2, uint8_t IN3, uint8_t IN4, uint8_t IR_LEFT, uint8_t IR_RIGHT, uint8_t SERVO, uint8_t TRIGGER_PIN, uint8_t ECHO_PIN, uint8_t S0, uint8_t S1, uint8_t S2, uint8_t S3, uint8_t sensorOut, RobotState initState, uint8_t k, uint8_t distance)

Constructor for Robot class.
- void init ()

Initialize robot hardware and pins.
- void run ()

Main robot operation function, called repeatedly in loop.

### 1.1.1 Detailed Description

Main robot control class that handles line following, obstacle detection and avoidance.

Generated by Doxygen

2

### 1.1.2 Constructor & Destructor Documentation

### 1.1.2.1 Robot() Robot::Robot (

uint8_t ENA,

uint8_t ENB,

uint8_t IN1,

uint8_t IN2,

uint8_t IN3,

uint8_t IN4,

uint8_t IR_LEFT,

uint8_t IR_RIGHT,

uint8_t SERVO,

uint8_t TRIGGER_PIN,

uint8_t ECHO_PIN,

uint8_t S0,

uint8_t S1,

uint8_t S2,

uint8_t S3,

uint8_t sensorOut,

RobotState initState,

uint8_t k,

uint8_t distance )

Constructor for Robot class.

Constructor implementation for Robot class.

Parameters

ENA | Enable pin for left motor
ENB | Enable pin for right motor
IN1 | Direction control pin 1 for left motor
IN2 | Direction control pin 2 for left motor
IN3 | Direction control pin 1 for right motor
IN4 | Direction control pin 2 for right motor
IR_LEFT | Left infrared sensor pin
IR_RIGHT | Right infrared sensor pin
SERVO | Servo motor control pin
TRIGGER_PIN | Ultrasonic sensor trigger pin
ECHO_PIN | Ultrasonic sensor echo pin
S0 | Color sensor frequency scaling selection pin S0
S1 | Color sensor frequency scaling selection pin S1
S2 | Color sensor photodiode selection pin S2
S3 | Color sensor photodiode selection pin S3
sensorOut | Color sensor output pin
initState | Initial state of the robot
k | Proportional control constant
distance | Threshold distance for obstacle detection in cm

Initializes all pins and parameters for the robot

2 File Documentation | 3

### 1.1.3 Member Function Documentation

### 1.1.3.1 init() void Robot::init ( )

Initialize robot hardware and pins.

Initialize all pins and components.

Sets up pin modes for motors, sensors, and initializes servo and LED matrix

### 1.1.3.2 run() void Robot::run ( )

Main robot operation function, called repeatedly in loop.

Main robot operation function.

State machine that controls robot behavior based on current state

The documentation for this class was generated from the following files:

- Robot.h
- Robot.cpp

## 2 File Documentation

### 2.1 Robot.cpp File Reference

Implementation of the Robot class methods.

#include "Robot.h"

Include dependency graph for Robot.cpp:

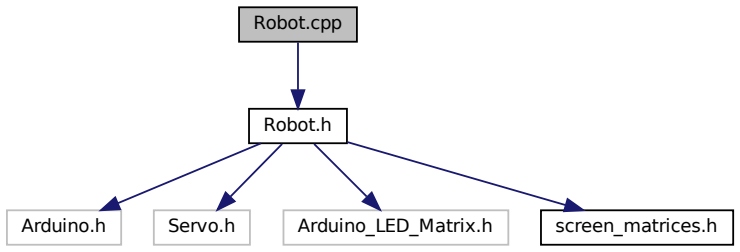
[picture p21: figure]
Robot.cpp; Robot.h; Arduino.h; Servo.h; Arduino_LED_Matrix.h; screen_matrices.h

4

### 2.1.1 Detailed Description

Implementation of the Robot class methods.

Author

Group C4

Date

2025

### 2.2 Robot.h File Reference

Robot class definition for line-following robot with obstacle detection.

#include <Arduino.h>

#include <Servo.h>

#include "Arduino_LED_Matrix.h" #include "screen_matrices.h" Include dependency graph for Robot.h:

Robot.h

Arduino.h | Servo.h | Arduino_LED_Matrix.h | screen_matrices.h

This graph shows which files directly or indirectly include this file:

## Robot.h

## Robot.cpp

Classes

- class Robot

Main robot control class that handles line following, obstacle detection and avoidance.

2.2 Robot.h File Reference | 5

Enumerations

- enum RobotState { FOLLOW_LINE , INSPECT_OBSTACLE , AVOID_OBSTACLE }

Defines the possible states of the robot.
- enum Colors { RED , BLUE , UNKNOWN }

Defines the colors that can be detected by the color sensor.
- enum Motion { FORWARD , LEFT , RIGHT }

Defines the motion direction of the robot.

### 2.2.1 Detailed Description

Robot class definition for line-following robot with obstacle detection.

Author

Group C4

Date

2025

### 2.2.2 Enumeration Type Documentation

### 2.2.2.1 Colors enum Colors

Defines the colors that can be detected by the color sensor.

Enumerator

RED | Red color
BLUE | Blue color
UNKNOWN | Unknown color

### 2.2.2.2 Motion enum Motion

Defines the motion direction of the robot.

Enumerator

FORWARD | Forward
LEFT | Left
RIGHT | Right

6

### 2.2.2.3 RobotState enum RobotState

Defines the possible states of the robot.

Enumerator

FOLLOW_LINE | Robot is following a line
INSPECT_OBSTACLE | Robot is inspecting an obstacle
AVOID_OBSTACLE | Robot is avoiding an obstacle

### 2.3 Robot.h

Go to the documentation of this file.

1
8 #ifndef ROBOT_H
9 #define ROBOT_H
10
11 #include <Arduino.h>
12 #include <Servo.h>
13 #include "Arduino_LED_Matrix.h" 14 #include "screen_matrices.h" 15
20 enum RobotState {
21 | FOLLOW_LINE,
22 | INSPECT_OBSTACLE,
23 | AVOID_OBSTACLE
24 };
25
30 enum Colors {
31 | RED,
32 | BLUE,
33 | UNKNOWN
34 };
35
40 enum Motion {
41 | FORWARD,
42 | LEFT,
43 | RIGHT
44 };
45
46
51 class Robot {
52 private:
53 | Servo myservo;
54 | ArduinoLEDMatrix matrix;
55 | RobotState state;
56 | uint8_t ENA, ENB, IN1, IN2, IN3, IN4;
57 | uint8_t IR_LEFT, IR_RIGHT, SERVO;
58 | uint8_t TRIGGER_PIN, ECHO_PIN;
59 | uint8_t S0, S1, S2, S3, sensorOut;
60 | uint32_t timerError;
61 | uint8_t k;
62 | uint8_t distance;
63 | Motion lastMotionState;
64 | Motion motionState;
65 | Motion avoidMotion;
69 | void followLine();
70
74 void avoidObstacle();
75
79 void inspectObstacle();
80
85 void motorLeft(short speed); 86
91 void motorRight(short speed); 92
97 bool checkDistance();
98
103 Colors checkColor();
104 public:

2.4 screen_matrices.h File Reference | 7

Robot(uint8_t ENA,
uint8_t ENB,
uint8_t IN1,
uint8_t IN2,
uint8_t IN3,
uint8_t IN4,
uint8_t IR_LEFT,
uint8_t IR_RIGHT,
uint8_t SERVO,
uint8_t TRIGGER_PIN,
uint8_t ECHO_PIN,
uint8_t S0,
uint8_t S1,
uint8_t S2,
uint8_t S3,
uint8_t sensorOut,
RobotState initState,
uint8_t k,
uint8_t distance);

void init();

void run();
156 };

158 #endif //ROBOT_H

### 2.4 screen_matrices.h File Reference

LED matrix display patterns for robot status indication.

This graph shows which files directly or indirectly include this file:

## screen_matrices.h

## Robot.h

## Robot.cpp

Variables

- const uint32_t stopSign [ ]

Stop sign pattern for LED matrix.
- const uint32_t forwardSign [ ]

Forward arrow pattern for LED matrix.
- const uint32_t rightSign [ ]

Right arrow pattern for LED matrix.
- const uint32_t leftSign [ ]

Left arrow pattern for LED matrix.

8

### 2.4.1 Detailed Description

LED matrix display patterns for robot status indication.

Author

Group C4

Date

2025

### 2.4.2 Variable Documentation

### 2.4.2.1 forwardSign const uint32_t forwardSign[ ]

Initial value:

= {
0x600f01f,
0x83fc7fe0,
0xf00f00f0
}

Forward arrow pattern for LED matrix.

Displays an upward arrow when robot is moving forward

### 2.4.2.2 leftSign const uint32_t leftSign[ ]

Initial value:

= {
0x400c01c,
0x3fc3fc1,
0xc00c0040
}

Left arrow pattern for LED matrix.

Displays a left-pointing arrow when robot is turning left

### 2.4.2.3 rightSign const uint32_t rightSign[ ]

Initial value:

= {
0x2003003,
0x83fc3fc0,
0x38030020
}

Right arrow pattern for LED matrix.

Displays a right-pointing arrow when robot is turning right

2.5 screen_matrices.h | 9

### 2.4.2.4 stopSign const uint32_t stopSign[ ]

Initial value:

= {
0xf010820,
0x42f42f42,
0x41080f0
}

Stop sign pattern for LED matrix.

Displays an octagonal stop sign pattern when obstacle is detected

### 2.5 screen_matrices.h

Go to the documentation of this file.

1
13 const uint32_t stopSign[] = {
14 | 0xf010820,
15 | 0x42f42f42,
16 | 0x41080f0
17 };
18
24 const uint32_t forwardSign[] = {
25 | 0x600f01f,
26 | 0x83fc7fe0,
27 | 0xf00f00f0
28 };
29
35 const uint32_t rightSign[] = {
36 | 0x2003003,
37 | 0x83fc3fc0,
38 | 0x38030020
39 };
40
46 const uint32_t leftSign[] = {
47 | 0x400c01c,
48 | 0x3fc3fc1,
49 | 0xc00c0040
50 };

## Index

AVOID_OBSTACLE
Robot.h, 6

BLUE
Robot.h, 5

Colors
Robot.h, 5

FOLLOW_LINE
Robot.h, 6
FORWARD
Robot.h, 5
forwardSign
screen_matrices.h, 8

init
Robot, 3
INSPECT_OBSTACLE
Robot.h, 6

LEFT
Robot.h, 5
leftSign
screen_matrices.h, 8

Motion
Robot.h, 5

RED
Robot.h, 5
RIGHT
Robot.h, 5
rightSign
screen_matrices.h, 8
Robot, 1
init, 3
Robot, 2
run, 3
Robot.cpp, 3
Robot.h, 4, 6
AVOID_OBSTACLE, 6
BLUE, 5
Colors, 5
FOLLOW_LINE, 6
FORWARD, 5
INSPECT_OBSTACLE, 6
LEFT, 5
Motion, 5
RED, 5
RIGHT, 5
RobotState, 6
UNKNOWN, 5
RobotState
Robot.h, 6
run
Robot, 3

screen_matrices.h, 7, 9
forwardSign, 8
leftSign, 8
rightSign, 8
stopSign, 8
stopSign
screen_matrices.h, 8

UNKNOWN
Robot.h, 5

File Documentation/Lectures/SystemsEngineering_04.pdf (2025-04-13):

Systems Engineering

Stefan Henkler | E-Mail: stefan.henkler@hshl.de

23.03.2022

Homework

### Consider your Microcontroller project from last semester

- Specify the blocks (bdd and ibd) on analysis level
- Use paper and pen
- In addition, if you have the possiblity, use the SysML tool papyros

### Readings

- Tim Weilkiens, “Systems Engineering with SysML/UML” (see: https://learning.oreilly.com/library/view/systems-engineering-with/9780123742742/)
- 4.5. Block diagrams (recap)
- 4.6. Parametric block diagrams

recap

23.03.2022 < 2 >

V Analysis and Design

### Models 1. Introduction 2. Methods 3. Analysis 4. Design 5. Advanced Design Concepts 6. Discussion & Summary 7. Bibliography

3

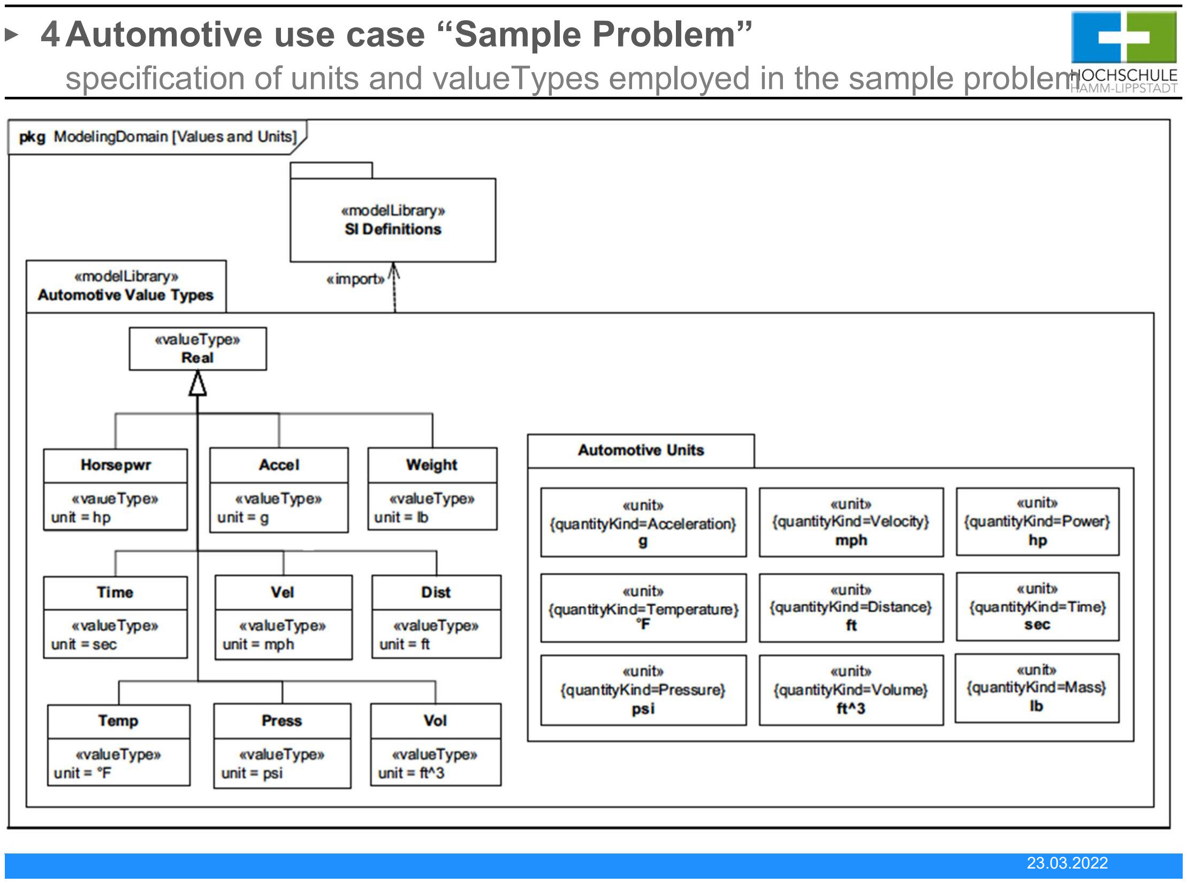
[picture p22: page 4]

Automotive use case “Sample Problem”
.. specification of units and valueTypes employed in the sample problem

4

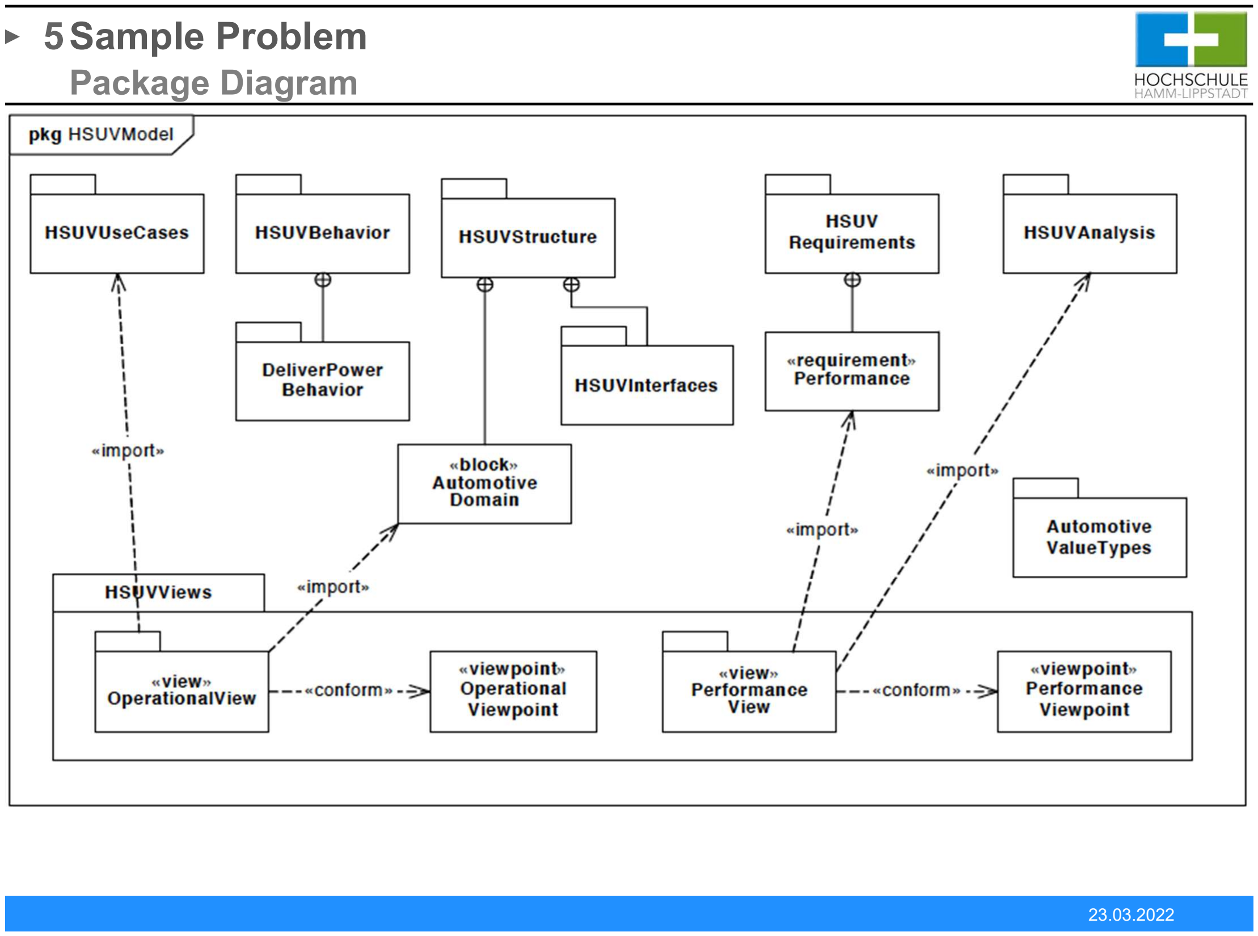
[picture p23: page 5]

Sample Problem
.. Package Diagram

5

Sample Problem

### ... See requirements lecture

Setting the context

6

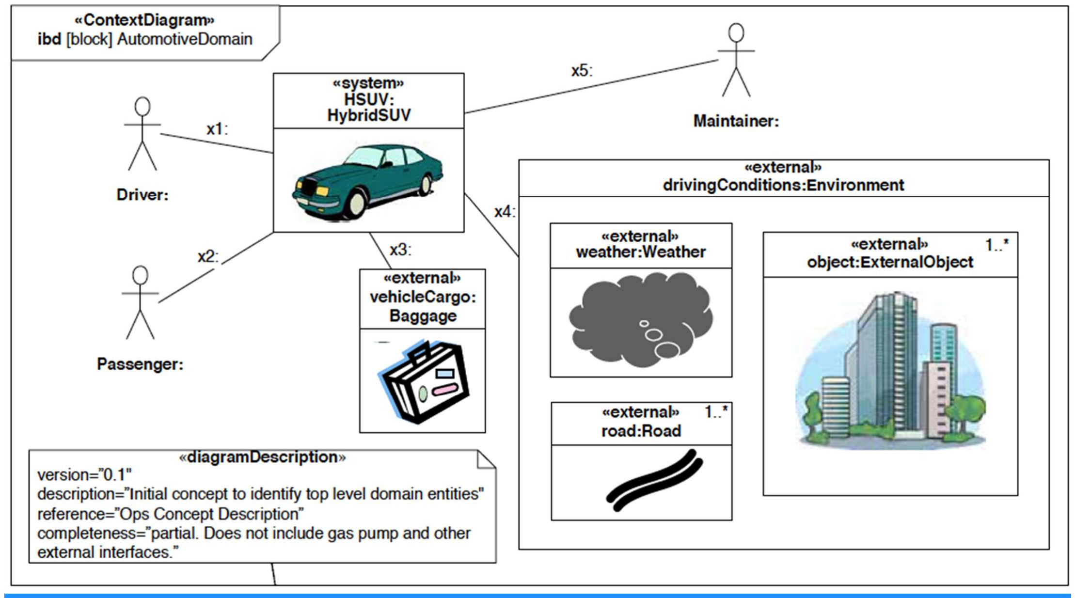
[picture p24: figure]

Sample Problem
.. Block Definition Diagram – Automotive Domain

7


Sample Problem
.. Block Definition Diagram – Hybrid SUV

8


Sample Problem

Internal Block Diagram - HSUV

9

Sample Problem
.. Bdd – Power Subsystem

10


Sample Problem

Ibb – Power Subsystem

11

Sample Problem

### Blocks Typing Ports in the Power Subsystem

Blocks Typing Ports

12


Sample Problem


### Use ports with flow properties to model the bus architecture

### Port Types with Flow Properties for the CAN Bus (Block Definition Diagram)

In Detail: Defining Ports and Flows

13

Sample Problem

### refinement of the Controller Area Network (CAN) bus architecture using ports Consider explicit structural allocation

Internal Block Diagram of the CAN-Bus

14


Sample Problem
.. Ports Fuel Tank

15


(2) Parametric Constraint Diagram
- Can be used to specify a network of constraints that represent mathematical expressions such as {F=m*a}
- constrain the physical properties of a system
- Constraints can also be used to identify critical performance parameters and their relationships to other parameters
- can be tracked throughout the system life cycle
- Constraint blocks define generic forms of constraints that can be used in multiple contexts
- Usually the constrained properties express quantitative characteristics of a system, but parametric models may also be used on non-quantitative properties.
- Time can be modeled as a property that other properties may be dependent on
- A time reference can be established by a local or global clock that produces a continuous or discrete time value property.
- Other values of time can be derived from this clock, by introducing delays and/or skew into the value of time
- Application
- Define dependencies between parameters
- Define system constraints
- Parametric constraints are typically used in combination with block diagrams.
- Can be used to support tradeoff analysis.

16

### Elements ConstraintBlock: A constraint


### block is defined by a keyword of «constraint» applied to a block definition. The properties of this block define the parameters of the constraint. Parametric diagrams include


### usages of constraint blocks to constrain the properties of another block. The usage of a constraint binds the parameters of the constraint, such as F, m, and a, to specific properties of a block, such as a mass, that provide values for

the parameters.

17


Usage

Example: Sample Problem

### parametric diagram showing how fuel flowrate is related

to FuelDemand and FuelPressure value properties.

Defining Fuel Flow Constraints

18


Sample Problem
.. Analysis Context – Constraint Blocks and its relations

19

(3) Activity Diagrams

### Activities specify sequential and concurrent behaviors that

are connected by control flows and object flows. Activities can be nested or atomic; in the latter case they

### are referred to as actions. Activity diagrams are analogous to Extended Functional

Flow Block Diagrams (EFFBDs).

### Application

- Can be used to specify the causal/functional behavior of a system.

20

Basic Actions

### AcceptEventAction/ SendSignalEvent

### Action


### InitialNode/ActivityFinal

### FlowFinal

21

Control Flow


### ControlFlow

### - DecisionNode/MergeNode

### - ForkNode/JoinNode

### InterruptibleActivityRegion

### Page connectors: used to connect flows across

multiple pages.

22

Object Flow (1/2)


- ObjectNode: items that are flowing through the activity and happen to be contained by the object node at the time the link exists.
- NoBuffer: tokens arriving at the node, which are refused by outgoing edges or refused by actions for object nodes, which are input pins, are discarded. Overwrite: a token arriving at a full

object node replaces the ones already there (a full object node has as many tokens as allowed by its upper bound).
- Optional/Required: the lower multiplicity must be equal to zero. Otherwise, the lower multiplicity must be greater than zero, which is called “required”.

Different types

23

Object Flow (2/2)


- Stream: supports the input and output of items while a behavior is executing, rather than only when the behavior starts and stops.
- Rate: specifies the rate over time that objects and values traverse the edge, that is, the rate they leave the source node and arrive at the target.
- Continuous: treated as infinitesimal (e.g.,water flowing a pipe) or entities sufficiently small enough to treat as continuously flowing (e.g., ball bearings in a factory).
- Discrete: a kind of Rate stereotype representing a rate of flow for items treated as individuals for the purpose of the application, for example, cars in a car factory.

24

Example
Continuous

25


Homework

### Consider your Microcontroller project from last semester

- Specify the parametric constraints and activity diagrams on analysis level
- Use paper and pen
- In addition, if you have the possiblity, use the SysML tool papyros

### Readings

- Tim Weilkiens, “Systems Engineering with SysML/UML” (see: https://learning.oreilly.com/library/view/systems-engineering-with/9780123742742/)
- 4.6. Parametric block diagrams and 4.8 Activity Diagram (recap)
- Further readings: all sections of chapter 4 that have not yet been covered

23.03.2022 < 26 >

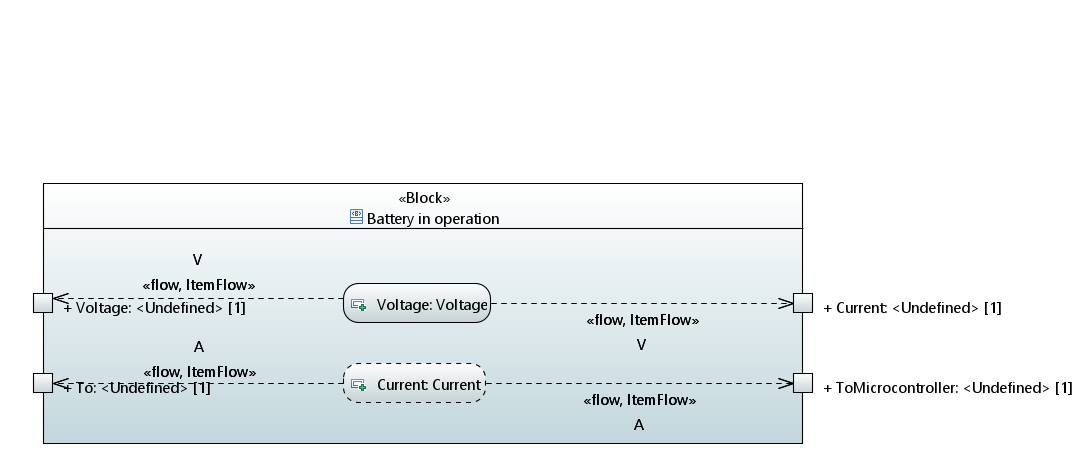
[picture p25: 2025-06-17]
Documentation/Papyrus/DiagramExports/PNG/Battery_Parametric.PNG

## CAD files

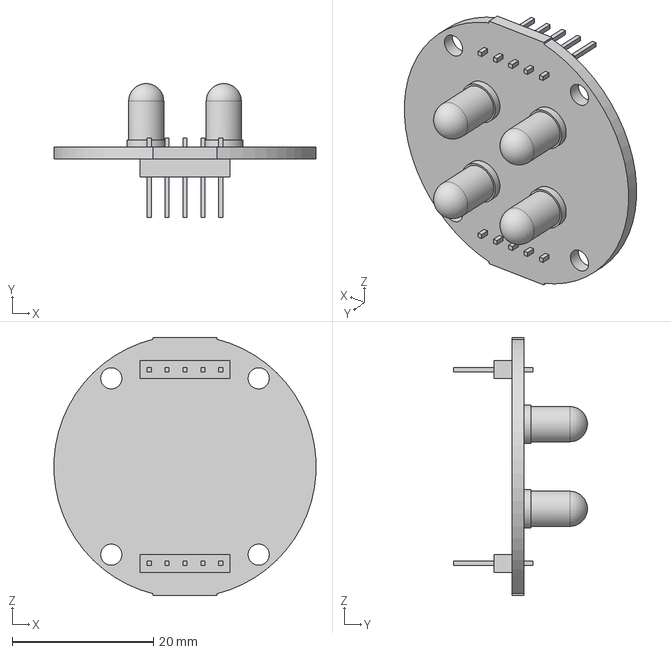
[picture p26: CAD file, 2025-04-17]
3DModels/Basic components/ColourSensor.step
37.1 x 19.0 x 36.6 mm

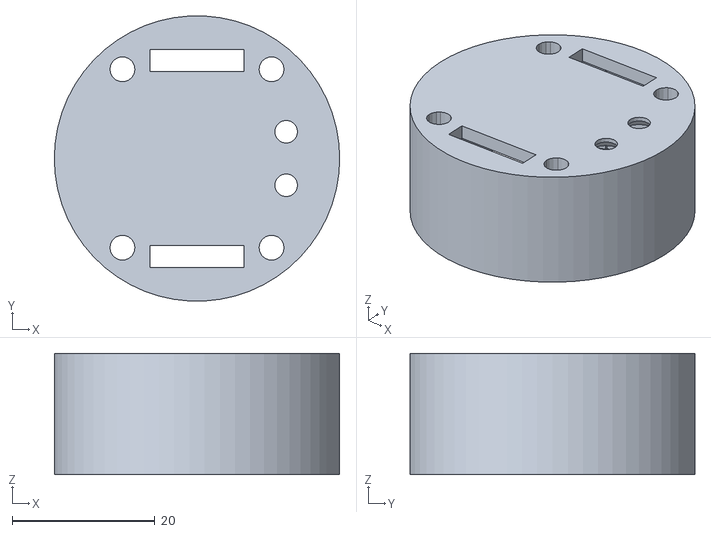
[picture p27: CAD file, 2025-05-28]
3DModels/Details to print/.stl/colorSensorHolder.stl
40.0 x 39.9 x 17.0

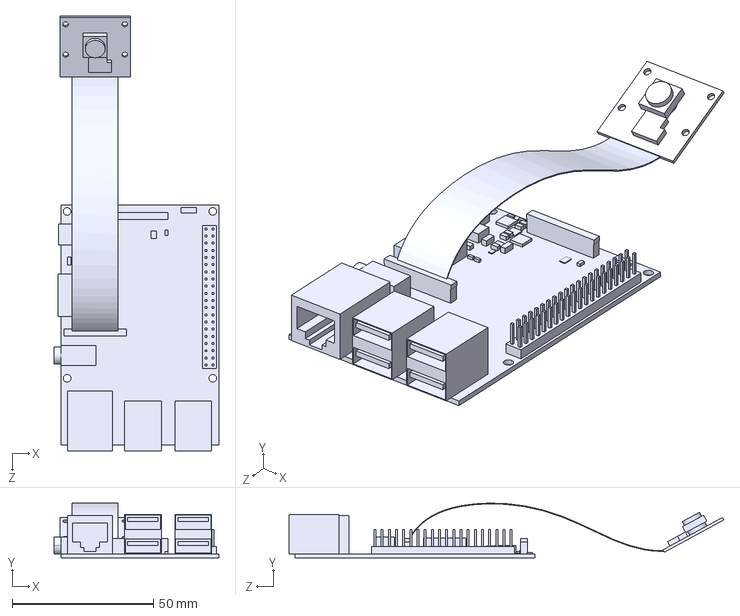
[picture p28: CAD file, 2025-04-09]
3DModels/Basic components/raspery-pi-pi-cam.STEP
58.4 x 19.4 x 154.0 mm

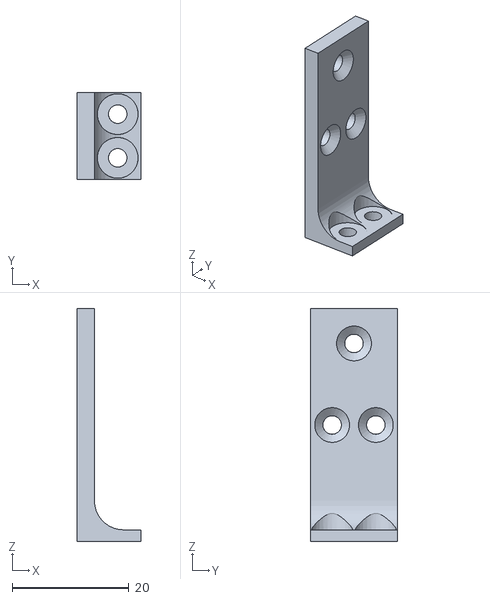
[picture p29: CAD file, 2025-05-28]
3DModels/Details to print/.stl/colorSensorHolder2.stl
11.0 x 15.0 x 40.0

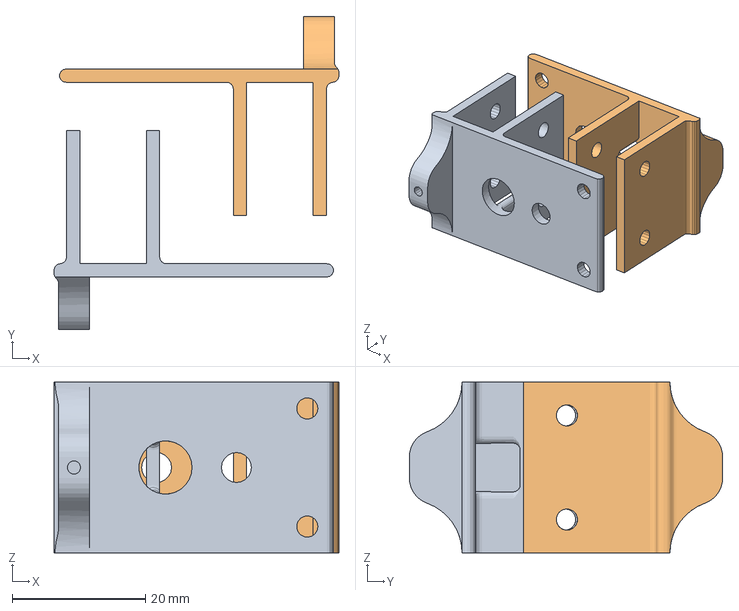
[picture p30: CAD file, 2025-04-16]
3DModels/Details to print/vertMotorHolder.3mf
42.8 x 47.1 x 25.7 mm
vertMotorHolder.stl x 2

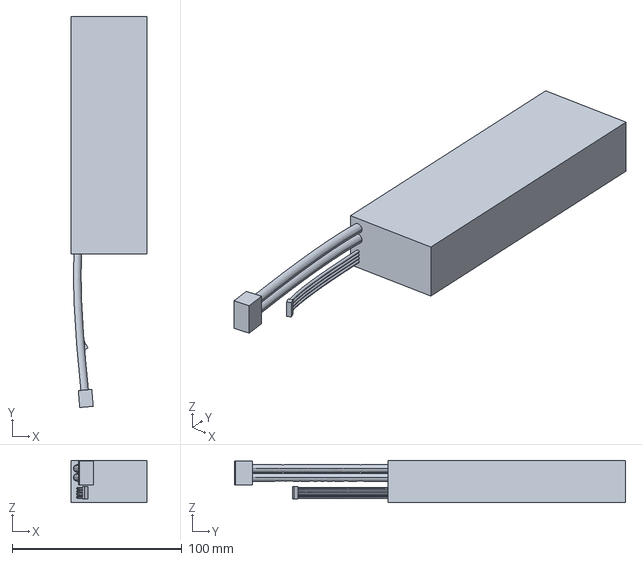
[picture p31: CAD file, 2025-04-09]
3DModels/Basic components/lipo-battery.stp
45.0 x 230.3 x 25.0 mm

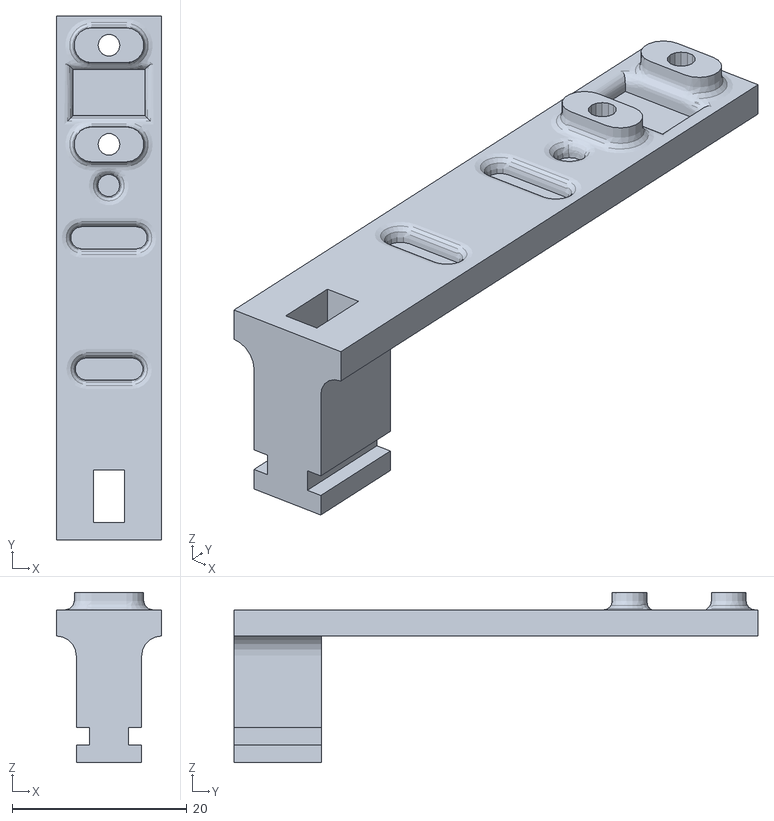
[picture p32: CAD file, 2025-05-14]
3DModels/Details to print/.stl/IRHolder_new.stl
12.0 x 60.0 x 19.5

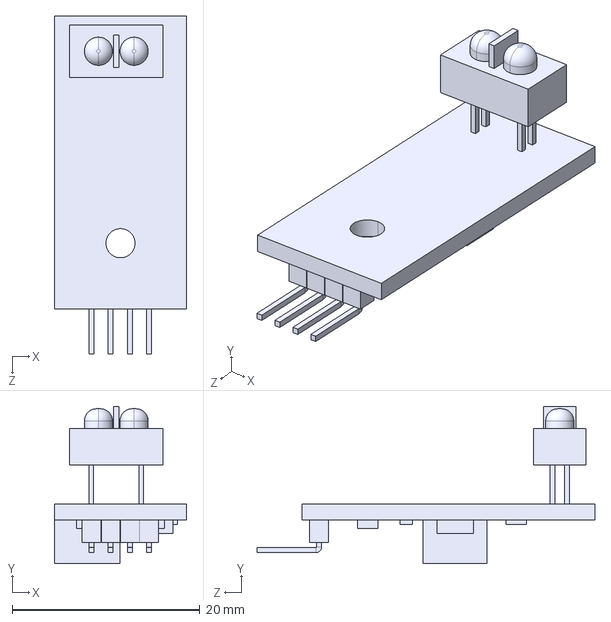
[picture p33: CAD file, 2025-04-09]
3DModels/Basic components/infrared-sensor.STEP
14.1 x 16.8 x 36.0 mm

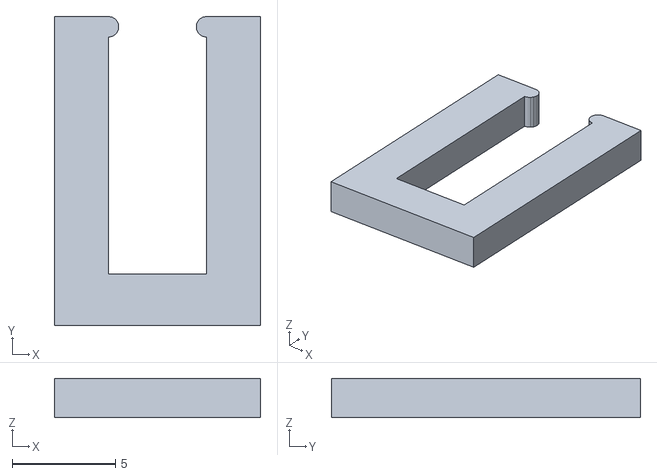
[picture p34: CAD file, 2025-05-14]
3DModels/Details to print/.stl/IRHolder_new2.stl
10.0 x 15.0 x 1.90

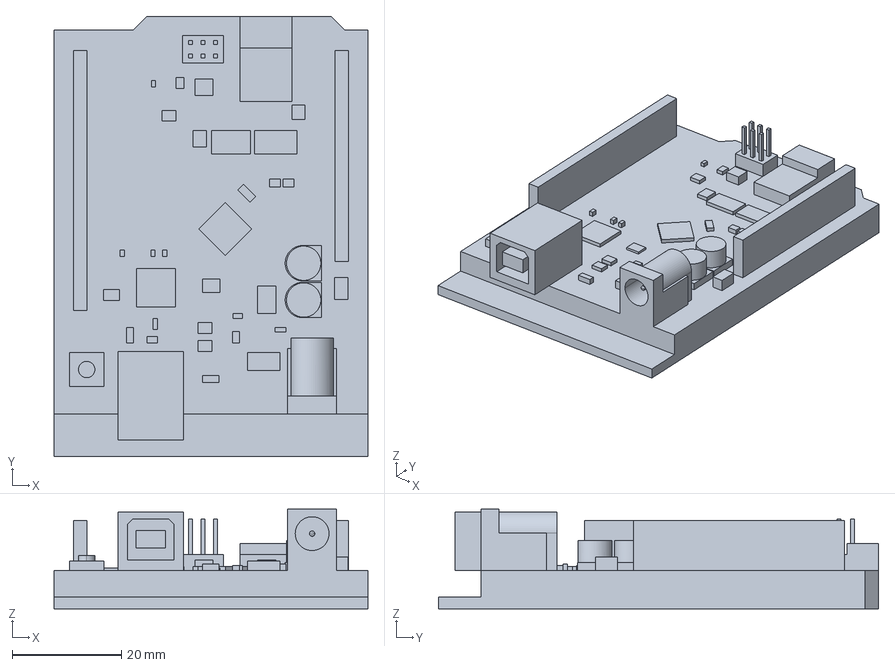
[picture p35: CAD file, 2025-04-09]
3DModels/Basic components/arduino.stp
57.5 x 80.7 x 18.3 mm

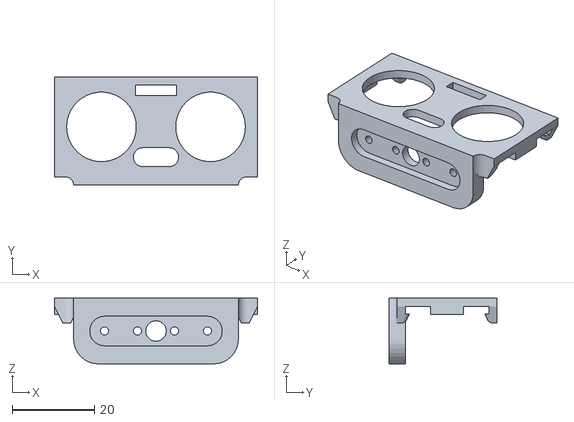
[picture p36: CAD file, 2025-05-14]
3DModels/Details to print/.stl/ultrasomicHolder.stl
49.3 x 26.3 x 16.0

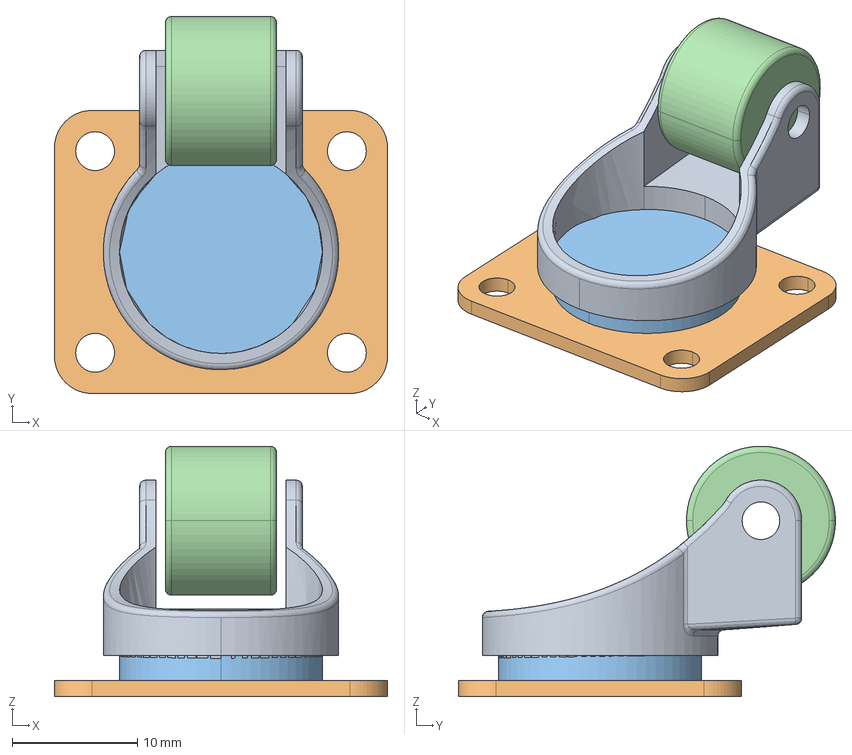
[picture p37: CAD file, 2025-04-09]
3DModels/Basic components/front-wheel.stp
26.6 x 30.1 x 20.0 mm

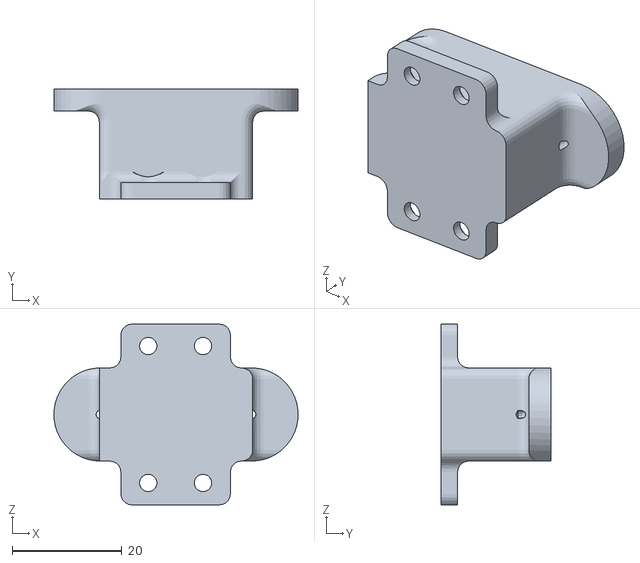
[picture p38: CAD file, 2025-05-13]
3DModels/Details to print/.stl/servoHolder.stl
44.5 x 20.0 x 33.0

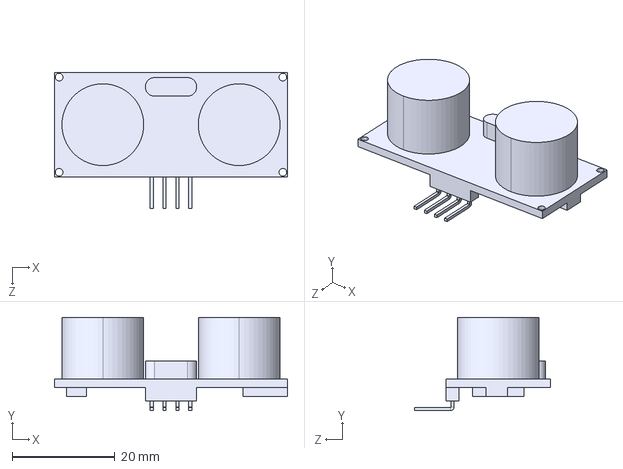
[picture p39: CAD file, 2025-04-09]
3DModels/Basic components/ultrasonic-sensor.STEP
45.3 x 18.2 x 26.4 mm

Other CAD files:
3DModels/Details to print/chassis.dwg
3DModels/Details to print/.stl/switchHolder.stl
3DModels/Basic components/motor-with-tire.stp
3DModels/Details to print/.stl/C4_IRsensorHolder2.stl
3DModels/Assembly.iam
3DModels/Basic components/ColorSensor.ipt
3DModels/Basic components/arduino.ipt
3DModels/Basic components/breadboard.ipt
3DModels/Basic components/breadboard.stp
3DModels/Basic components/chassis.ipt
3DModels/Basic components/chassis.stp
3DModels/Basic components/front-wheel.ipt
3DModels/Basic components/infrared-sensor-new.STEP
3DModels/Basic components/lipo-battery.ipt
3DModels/Basic components/motor-with-tire.ipt
3DModels/Basic components/motor-with-tire_MIR.ipt
3DModels/Basic components/motorcontroler.STEP
3DModels/Basic components/motorcontroler.ipt
3DModels/Details to print/.ipt/IRHolder_new.ipt
3DModels/Details to print/.ipt/IRHolder_new2.ipt
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

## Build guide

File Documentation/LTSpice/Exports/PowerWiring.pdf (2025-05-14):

## Driver

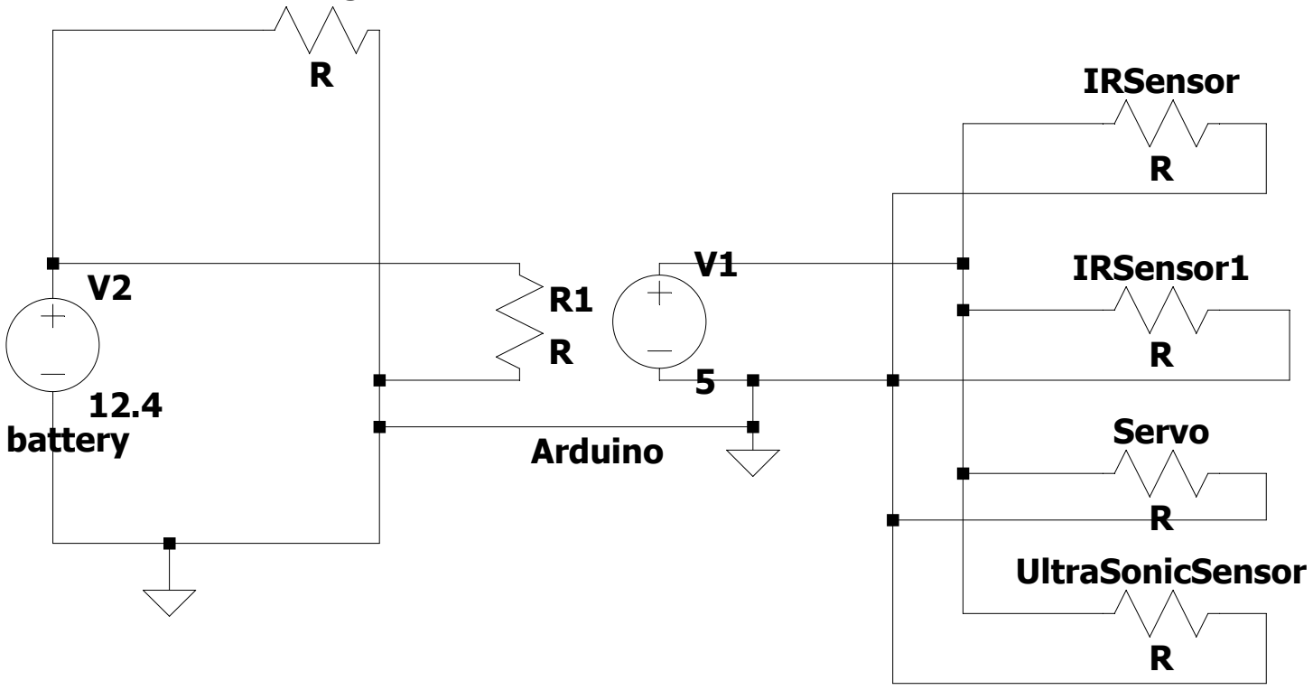
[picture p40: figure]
R IRSensor; IRSensor1; Servo; R UltraSonicSensor; Arduino battery

## .tran 1

## Sensors

--- C:\Users\petr.lavrenov\Documents\GitHub\Prototyping-SS25-Team-C4\Documentation\LTSpice\Files\PowerWiring.asc ---

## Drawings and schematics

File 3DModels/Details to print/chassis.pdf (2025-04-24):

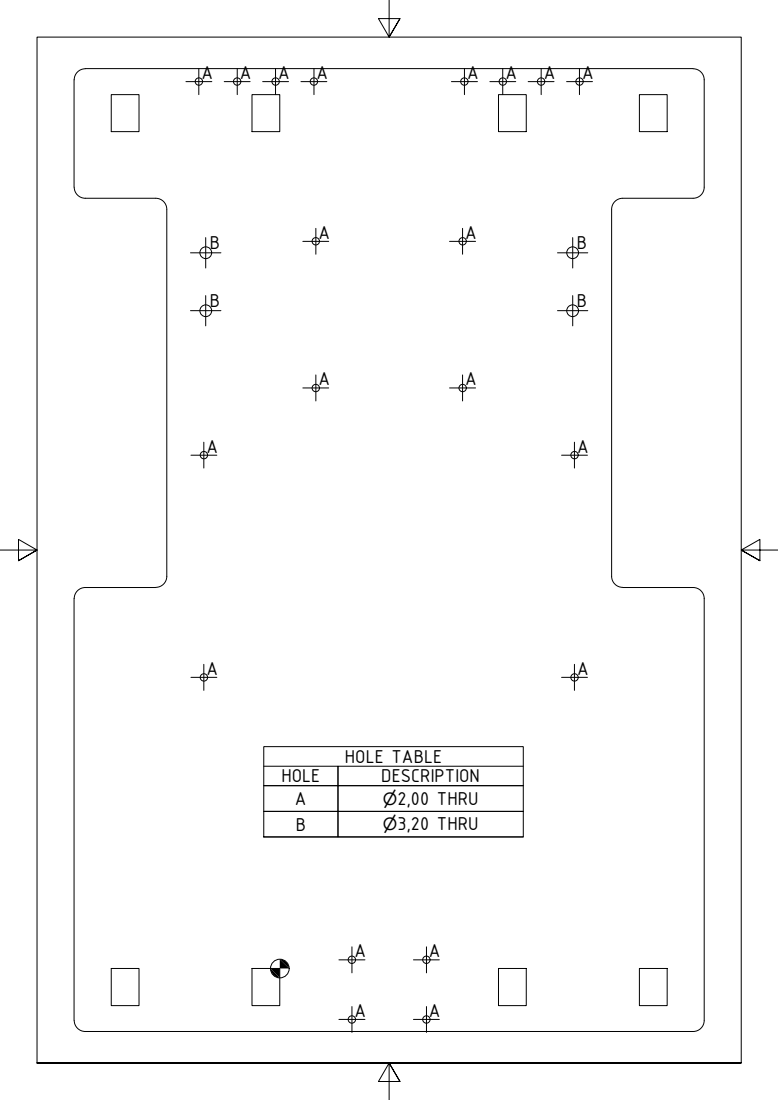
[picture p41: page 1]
HOLE TABLE

HOLE | DESCRIPTION
A | ⌀2,00 THRU
B | ⌀3,20 THRU

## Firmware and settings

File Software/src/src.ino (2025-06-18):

/**
 * @file src.ino
 * @brief Main Arduino sketch for line-following robot with obstacle detection
 * @author Group C4
 * @date 2025
 */
#include "Robot.h"

/**
 * @name Motor Control Pins
 * @{
 */
#define ENA 5         /**< Enable pin for left motor (PWM) */
#define ENB 10        /**< Enable pin for right motor (PWM) */
#define IN1 13        /**< Direction control pin 1 for left motor */
#define IN2 12        /**< Direction control pin 2 for left motor */
#define IN3 9         /**< Direction control pin 1 for right motor */
#define IN4 8         /**< Direction control pin 2 for right motor */
/** @} */

// Sensor pins
#define IR_LEFT 7     /**< Left infrared sensor pin */
#define IR_RIGHT 6    /**< Right infrared sensor pin */
#define SERVO 11      /**< Servo motor control pin */
#define TRIGGER_PIN 2 /**< Ultrasonic sensor trigger pin */
#define ECHO_PIN 3    /**< Ultrasonic sensor echo pin */

// Color sensor pins (not connected in current implementation)
#define S0 A0        /**< Color sensor frequency scaling selection pin S0 */
#define S1 A1        /**< Color sensor frequency scaling selection pin S1 */
#define S2 A2        /**< Color sensor photodiode selection pin S2 */
#define S3 A3        /**< Color sensor photodiode selection pin S3 */
#define sensorOut A4 /**< Color sensor output pin */

// Robot parameters
#define initState FOLLOW_LINE /**< Initial state of the robot */
#define k 80               /**< Proportional control constant */

/**
 * @brief Robot instance with all pin and parameter configurations
 */
Robot robot(ENA, ENB, IN1, IN2, IN3, IN4, IR_LEFT, IR_RIGHT, SERVO, TRIGGER_PIN, ECHO_PIN, S0, S1, S2, S3, sensorOut, initState, k);

/**
 * @brief Setup function, runs once at startup
 * 
 * Initializes serial communication and robot hardware
 */
void setup() {
  Serial.begin(9600);  // Initialize serial communication
  robot.init();        // Initialize robot hardware
}

/**
 * @brief Main loop function, runs repeatedly
 * 
 * Calls the robot's run method to execute the state machine
 */
void loop() {
  robot.run();  // Run the robot's state machine
}

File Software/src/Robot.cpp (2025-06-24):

/**
 * @file Robot.cpp
 * @brief Implementation of the Robot class methods
 * @author Group C4
 * @date 2025
 */

#include "Robot.h"

/**
 * @brief Constructor implementation for Robot class
 * 
 * Initializes all pins and parameters for the robot
 */
Robot::Robot(uint8_t ENA,
             uint8_t ENB,
             uint8_t IN1,
             uint8_t IN2,
             uint8_t IN3,
             uint8_t IN4,
             uint8_t IR_LEFT,
             uint8_t IR_RIGHT,
             uint8_t SERVO,
             uint8_t TRIGGER_PIN,
             uint8_t ECHO_PIN,
             uint8_t S0,
             uint8_t S1,
             uint8_t S2,
             uint8_t S3,
             uint8_t sensorOut,
             RobotState initState,
             uint8_t k)
  : ENA(ENA), ENB(ENB), IN1(IN1), IN2(IN2),
    IN3(IN3), IN4(IN4), IR_LEFT(IR_LEFT), IR_RIGHT(IR_RIGHT),
    SERVO(SERVO), TRIGGER_PIN(TRIGGER_PIN), ECHO_PIN(ECHO_PIN), state(initState),
    S0(S0), S1(S1), S2(S2), S3(S3), sensorOut(sensorOut), k(k), distance(distance), motionState(FORWARD), lastMotionState(FORWARD),lastSeenDirection(FORWARD), avoidMotion(RIGHT) {}


/**
 * @brief Initialize all pins and components
 * 
 * Sets up pin modes for motors, sensors, and initializes servo and LED matrix
 */
void Robot::init() {
  Serial.begin(9600);

  // Set motor control pins as outputs
  pinMode(ENA, OUTPUT);
  pinMode(ENB, OUTPUT);
  pinMode(IN1, OUTPUT);
  pinMode(IN2, OUTPUT);
  pinMode(IN3, OUTPUT);
  pinMode(IN4, OUTPUT);

  // Set IR sensors as inputs
  pinMode(IR_LEFT, INPUT);
  pinMode(IR_RIGHT, INPUT);

  // Set ultrasonic sensor pins
  pinMode(TRIGGER_PIN, OUTPUT);
  pinMode(ECHO_PIN, INPUT);

  // Set color sensor pins
  pinMode(S0, OUTPUT);
  pinMode(S1, OUTPUT);
  pinMode(S2, OUTPUT);
  pinMode(S3, OUTPUT);
  pinMode(sensorOut, INPUT);

  // Set frequency scaling to 20% for color sensor
  digitalWrite(S0, HIGH);
  digitalWrite(S1, LOW);

  // Initialize servo and LED matrix
  myservo.attach(SERVO);
  matrix.begin();

  // Initialize error timer
  timerError = millis();
}

/**
 * @brief Main robot operation function
 * 
 * State machine that controls robot behavior based on current state
 */
void Robot::run() {
  switch (state) {
    case FOLLOW_LINE:
      // Check if obstacle is detected
      if (checkDistance(15)) {
        // Change state to inspect obstacle
        state = INSPECT_OBSTACLE;
        break;
      }
      // Continue following the line
      followLine();
      break;
    case INSPECT_OBSTACLE:
      // Inspect the detected obstacle
      inspectObstacle();
      break;
    case AVOID_OBSTACLE:
      // Avoid the obstacle
      avoidObstacle();
      break;
  }
  // Small delay for stability
  delay(1);
}

/**
 * @brief Line following algorithm implementation
 * 
 * Uses IR sensors to detect the line and adjusts motors accordingly
 */
void Robot::followLine() {
  // Read IR sensor values
  bool left = digitalRead(IR_LEFT);
  bool right = digitalRead(IR_RIGHT);

 if (left && !right) {
  motionState = LEFT;
  lastSeenDirection = LEFT;
} else if (!left && right) {
  motionState = RIGHT;
  lastSeenDirection = RIGHT;
} else if (!left && !right) {
  // Use lastSeenDirection instead
  motionState = lastSeenDirection;
} else {
  // Both on line 
  motionState = FORWARD;
}
  switch (motionState) {
    // Left sensor on line, right sensor off line - turn left
    case LEFT:
      {
        if (lastMotionState != motionState)
          timerError = millis();
        uint8_t speed = int(k * abs(millis() - timerError)) / 1000;
        if (speed >= 30)
          speed = 30;
        motorLeft(30 - speed);      // Left motor backward
        motorRight(-70 + speed);     // Right motor forward
        myservo.write(105);          // Turn servo left
        matrix.loadFrame(leftSign);  // Display left arrow

        lastMotionState = motionState;
        break;
      }
    // Right sensor on line, left sensor off line - turn right, the coefficients change because no two motors are the same in this world
    case RIGHT:
      {
        if (lastMotionState != motionState)
          timerError = millis();
        uint8_t speed = int(k * abs(millis() - timerError)) / 1000;
        if (speed >= 30)
          speed = 30;
        motorLeft(-70 + speed);       // Left motor forward
        motorRight(30 - speed);      // Right motor backward
        myservo.write(75);            // Turn servo right
        matrix.loadFrame(rightSign);  // Display right arrow
        lastMotionState = motionState;
        break;
      }
    // Both sensors off line - go straight
    case FORWARD:
      {
        if (lastMotionState != motionState)
          timerError = millis();
        uint8_t speed = int(k * abs(millis() - timerError)) / 1000;
        if (speed >= 30)
          speed = 30;
        motorLeft(-50 - speed);         // Left motor forward
        motorRight(-50 - speed);        // Right motor forward
        myservo.write(90);              // Center servo
        timerError = millis();          // Reset error timer
        matrix.loadFrame(forwardSign);  // Display forward arrow
        lastMotionState = motionState;
        break;
      }
  }
}

/**
 * @brief Obstacle avoidance algorithm
 * 
 * Controls the robot's movement to navigate around detected obstacles
 */
void Robot::avoidObstacle() {
  switch (avoidMotion) {
    case RIGHT:
      motorLeft(-60);
      motorRight(40);
      if ((millis() - timerError) > 600) {
        avoidMotion = FORWARD;
        timerError = millis();
      }
      break;
    case LEFT:
      motorLeft(0);
      motorRight(-60);
       if (digitalRead(IR_LEFT) || digitalRead(IR_RIGHT)) {
        motorLeft(-60);
        motorRight(60);
        state = FOLLOW_LINE;
      }
      if (checkDistance(20)) {
        avoidMotion = FORWARD;
        timerError = millis();
      }
      if (digitalRead(IR_LEFT) || digitalRead(IR_RIGHT)) {
        motorLeft(-60);
        motorRight(60);
        state = FOLLOW_LINE;
      }
      break;
    case FORWARD:
      motorLeft(-60);
      motorRight(-60);
      if ((millis() - timerError) > 800) {
        avoidMotion = LEFT;
        timerError = millis();
      }
      if (digitalRead(IR_LEFT) || digitalRead(IR_RIGHT)) {
        motorLeft(-60);
        motorRight(60);
        state = FOLLOW_LINE;
      }
      break;
  }
}
/**
 * @brief Inspect detected obstacle
 * 
 * Checks if obstacle is still present, returns to line following if not
 */
void Robot::inspectObstacle() {
  // If obstacle is no longer detected, return to line following
  if (!checkDistance(15))
    state = FOLLOW_LINE;
  else
    switch (checkColor()) {
      case RED:
        motorLeft(60);
        motorRight(80);
        delay(400);
        state = AVOID_OBSTACLE;
        avoidMotion = RIGHT;
        timerError = millis();
        myservo.write(0);
        break;
      case BLUE:
        followLine();
        break;
      case UNKNOWN:
        followLine();
        break;
    }
}
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

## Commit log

2025-04-09 Add basic components
    [arduino.stp, breadboard.stp, chassis.stp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]
2025-04-09 Assembly init commit
    [Assembly.iam]
2025-04-13 Add converted components step->ipt
    [arduino.ipt, breadboard.ipt, chassis.ipt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]
2025-04-13 Create vert motor holder
    [Assembly.iam, vertMotorHolder.ipt, vertMotorHolder.stl]
2025-04-16 Continue work on the 3d models
    [Assembly.iam, batteryHolder.ipt, batteryHolder.stl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]
2025-04-16 More 3d modelling
    [Assembly.iam, IRsensorHolder.0001.ipt, IRsensorHolder.ipt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]
2025-04-16 More modelling
    [Assembly.iam, IRsensorHolder.stl, IRsensorHolder2.stl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]
2025-04-16 Update battery holder
    [batteryHolder.ipt, batteryHolder.stl]
2025-04-16 Update some parts due to afterprint mismatch
    [Assembly.iam, IRsensorHolder2.0003.ipt, IRsensorHolder2.0004.ipt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]
2025-04-17 Update assembly
    [Assembly.iam, batteryHolder.ipt]
2025-04-17 Add colour sensor model for reference
    [Assembly.iam, ColorSensor.ipt, ColourSensor.step]
2025-04-18 Add assembly pic
    [Assembly.iam, motorcontroler.ipt]
2025-04-20 Remove unneeded files
    [IRsensorHolder.0001.ipt, IRsensorHolder2.0004.ipt, lipo-battery.0001.ipt]
2025-04-20 Create Arduino IDE project
2025-04-20 Restructure folders. Rename some files
    [C4_IRsensorHolder.stl, C4_IRsensorHolder2.stl, C4_batteryHolder.stl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]
2025-04-23 added use case diagram
2025-04-23 i dont remember what i changed, will look at later
    definetely something in diagrams, but it all looks the same and i need to switch machines
2025-04-24 Update models
    [Assembly.iam, chassis.ipt]
2025-04-24 Create chassis design
    [chassis.dwg]
2025-04-30 Create switch holder
    [switchHolder.ipt, switchHolder.stl]
2025-04-30 added a use case diagram
    maybe some other shit, its just in diagrams, who cares
2025-05-13 Create Servo Holder
    [servoHolder.ipt, servoHolder.stl]
2025-05-14 Make an ultrasonic holder
    [Assembly.iam, ultrasomicHolder.ipt, ultrasomicHolder.stl]
2025-05-14 Added electrical wiring LTSpice
2025-05-14 Create new ir sensor holders
    [Assembly.iam, IRHolder_new.ipt, IRHolder_new.stl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]
2025-05-28 Create color sensor holder
    [Assembly.iam, IRHolder_new.ipt, IRHolder_new2.ipt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]
2025-06-04 changed some shit, it doesnt work, but (description)
    1)we should add recurrent states to the line following, so the timer zeroes out on the state change
    2)we should Implement speed function to the moving forward states.
2025-06-06 added switch state for Follow Line
    For improved diff control
2025-06-06 added sketch of avoid obstacle+ motion state update
    [Robot.cpp]
2025-06-13 avoid obstacle doesnt work yet
    But everything around it does for now
    [Robot.cpp, src.ino]
2025-06-18 avoid obstacle "works" read description
    1) getting on the line would be easier if we tracked the inner side
    2)still not that great avoiding, needs more tuning, but it has done it
    [Robot.cpp, src.ino]
2025-06-20 Avoid and follow line work as good as i can ask
    sometimes detect doesnt work as needed
    [Robot.cpp]
2025-07-07 added the cut png
